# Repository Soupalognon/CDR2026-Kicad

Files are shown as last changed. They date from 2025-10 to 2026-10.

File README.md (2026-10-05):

# Robot CDF 2026

Carte électronique principale du robot **Wall-A**, conçu pour la **Coupe de France de Robotique 2026**.

<p align="center">
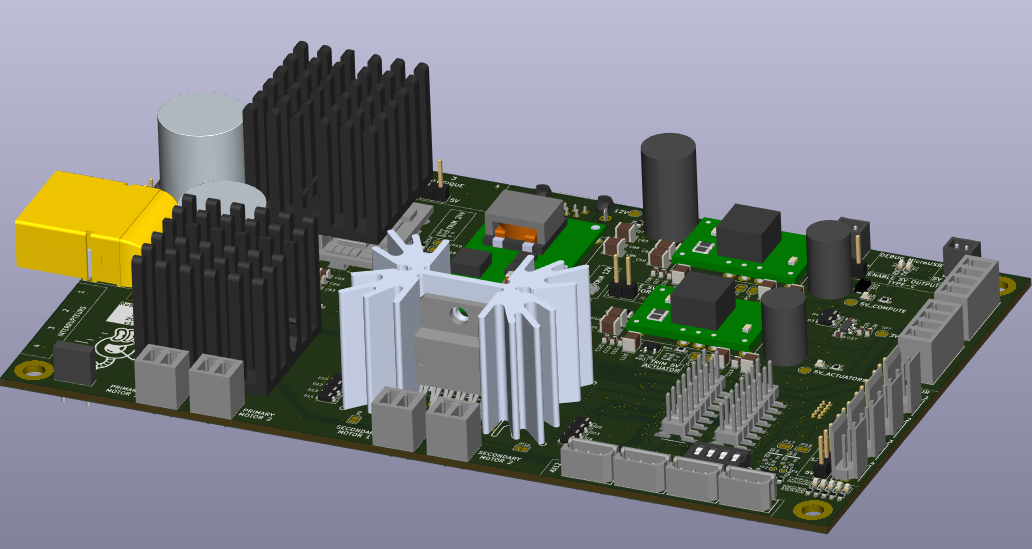
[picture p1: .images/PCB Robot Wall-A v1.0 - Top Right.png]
Vue 3D du PCB Wall-A v1.0
  
</p>

## Description

Ce PCB regroupe tout ce dont le robot a besoin pour fonctionner :

- **Alimentation** : génère les rails 24 V, 12 V, 5 V et 3,3 V à partir de la batterie
- **Moteurs et actionneurs** : commande des moteurs des roues, des moteurs secondaires et des servomoteurs
- **Capteurs** : encodeurs, capteurs de distance, interrupteurs et sondes de température
- **Contrôle bas niveau** : un microcontrôleur STM32F407 pilote le tout en temps réel
- **Liaison avec le PC embarqué** : USB et Ethernet pour le haut niveau. La prise USB Type-C du PC embarqué est une **sortie d'alimentation 5 V**

### Alimentation

La carte est alimentée par la batterie (LiPo 4S 14.8V, connecteur XT90) avec une tension d'entrée de 16 V à 24 V. Elle génère cinq rails avec trois types de convertisseurs :

| Rail | Type de convertisseur | Composant | Courant | Utilisation |
|---|---|---|---|---|
| 24 V | Élévateur (boost) | Module DC/DC ABB ABXS005 | 5,4 A | Moteurs des roues |
| 12 V | Abaisseur (buck) | TI PTN78020W | 5,8 A | Actionneurs (servomoteurs, ...) |
| 5 V actionneurs | Abaisseur (buck) | TI PTN78060W | 3,5 A | Actionneurs (servomoteurs, pompes, canon, télémètres, Lidar, ...) |
| 5 V calcul | Abaisseur (buck) | TI PTN78060W | 3,5 A | PC embarqué et µC |
| 3,3 V | Régulateur linéaire (LDO) | TI TLV75533P | | Logique du µC |

Les rails 24 V, 12 V et 5 V sont réglables par potentiomètre. Les rails 24 V, 12 V et 5 V actionneurs peuvent être activés par le µC. Les rails 5 V et 12 V sont aussi disponibles en sortie sur connecteurs.

### Contrôleurs moteurs

| Moteurs | Driver | Alimentation | Détails |
|---|---|---|---|
| 2 moteurs principaux (roues) | TI DRV8262, double pont en H | 24 V | Transmotec PD4266-24-17-BFEC, avec encodeurs 5 V |
| 2 moteurs secondaires | ST L298N, double pont en H | 5 V ou 12 V | 2 A maximum en continu par moteur |
| 4 servomoteurs AX12/AX18 | Bus série half-duplex (UART) avec adaptation de niveau 3,3 V / 5 V | 12 V | |
| 4 servomoteurs PWM | Signal PWM direct du µC | 5 V ou 12 V | |

Le µC mesure le courant des deux drivers et la température sous chacun d'eux.

### Capteurs

| Capteur | Quantité | Interface | Détails |
|---|---|---|---|
| Encodeurs | 2 | 5 V | Gauche et droite |
| Capteurs de distance Pulse Width | 4 | Largeur d'impulsion | |
| Capteurs de distance analogiques | 4 | ADC, 0 - 3,3 V | |
| Interrupteurs | 4 | Tout ou rien (on/off) | |
| Sondes de température internes | 3 | Thermistances CTN, ADC | Sous le driver moteur principal, sous le driver moteur secondaire, près des alimentations 12 V et 24 V |

### Communications et debug

| Interface | Détails | Utilisation |
|---|---|---|
| USB FS 12 Mb/s | Connecteur USB Type-C | PC embarqué. Cette prise est aussi une **sortie d'alimentation 5 V** |
| Ethernet 100 Mb/s | PHY LAN8742A + RJ45 | PC embarqué |
| UART 115 kbaud | FT231XS (USB-UART) sur micro-USB | Debug |
| Pin headers | Toutes les broches du µC | Accès direct au µC |
| LEDs | 5 LEDs connectées au µC | Debug |

### Informations générales

Le firmware du microcontrôleur est dans le dépôt [CDR2026-Software](https://github.com/Soupalognon/CDR2026-Software).

|  |  |
|---|---|
| Version | v1.0 (septembre 2025) |
| Dimensions | 170 × 100 mm |
| PCB | 4 couches, 1,6 mm |
| Logiciel | KiCad 9 |
| Auteurs | GDU, THO |

## Images

| Dessus | Dessous |
|:---:|:---:|
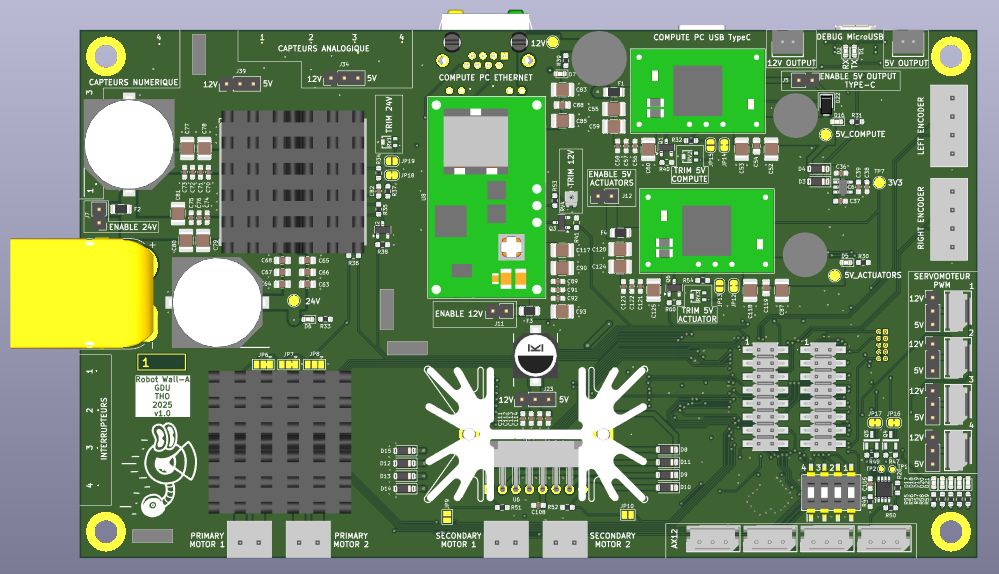
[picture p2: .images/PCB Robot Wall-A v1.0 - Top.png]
Dessus
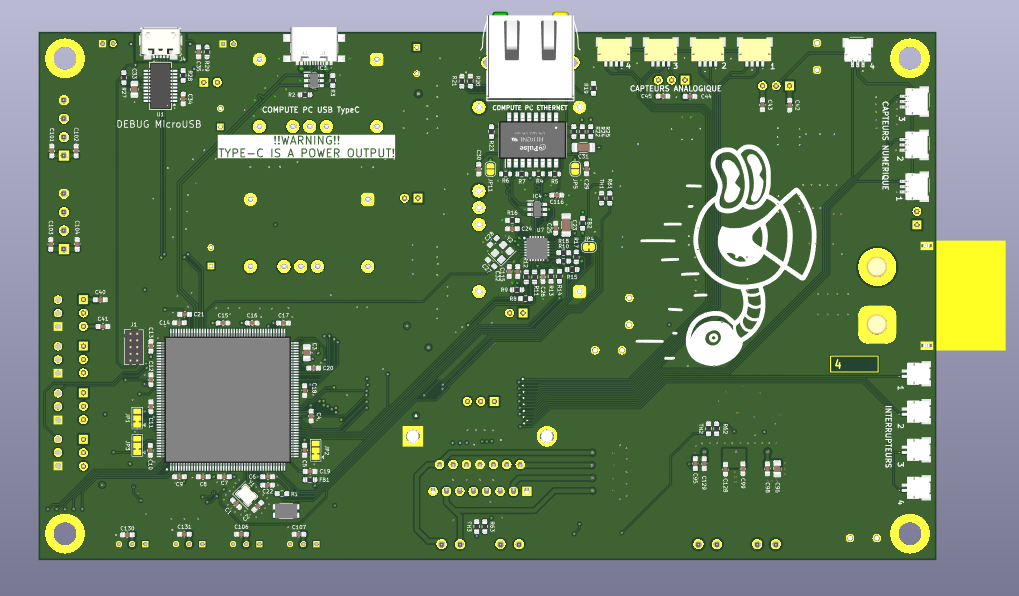
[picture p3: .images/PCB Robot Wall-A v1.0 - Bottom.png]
Dessous
|  |  |
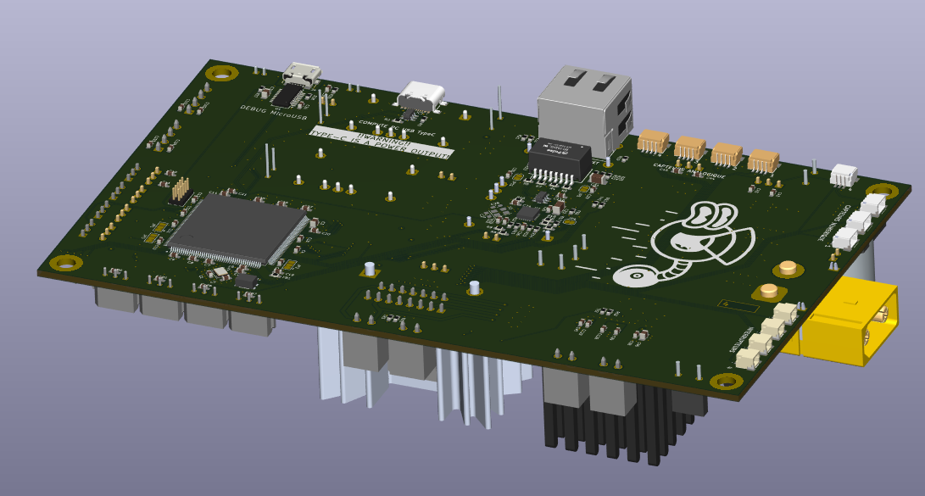
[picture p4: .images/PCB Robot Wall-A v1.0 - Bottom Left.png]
Vue 3D dessous
| Vue 3D dessus |  |

## Composants principaux

| Fonction | Composant |
|---|---|
| Microcontrôleur | STM32F407IGT6 |
| Alimentation 24V | Module DC/DC ABB ABXS005 |
| Alimentation 12V | TI PTN78020W |
| Alimentations 5V (calcul et actionneurs) | 2 × TI PTN78060W |
| Alimentation 3,3V | TI TLV75533P |
| Driver moteurs principaux | TI DRV8262 |
| Driver moteurs secondaires | ST L298N |
| Ethernet | PHY LAN8742A + transformateur H1102NL + RJ45 |
| USB PC embarqué | Connecteur USB Type-C |
| Debug | FT231XS (USB-UART) sur micro-USB |

La liste complète est dans la BOM : [Robot WallA.xlsx](Robot%20WallA/_output/Robot%20WallA.xlsx).

## Organisation du projet

Le schéma est hiérarchique : la feuille racine contient quatre blocs, eux-mêmes découpés en sous-feuilles.

| Bloc | Sous-feuilles |
|---|---|
| `Power` | `Power_Boost_24V`, `Power_Buck_12V`, `Power_Buck_5V_Actuators`, `Power_Buck_5V_Compute` |
| `MCU` | `MCU_Core`, `MCU_Config`, `MCU_Debug`, `MCU_GPIO`, `MCU_Peripherals` |
| `Motor` | `Motor_WheelDriver`, `Motor_Actuators`, `Motor_Encoders` |
| `Sensors` | |

```
.
├── .images/                 Captures du PCB utilisées dans ce README
├── Docs/                    Documents de référence et configuration de commande JLCPCB
├── Robot WallA/             Projet KiCad
│   ├── Robot WallA.kicad_pro / .kicad_sch / .kicad_pcb
│   ├── _Libraries/          Symboles, empreintes et modèles 3D spécifiques
│   └── _output/             Fichiers de fabrication
│       ├── Fab/ et Fab.zip      Gerbers et perçages
│       ├── Robot WallA.pdf      Schéma
│       ├── Robot WallA.xlsx     BOM
│       └── ibom.html            BOM interactive
├── LICENSE
└── README.md
```

## Fabrication

Les fichiers de fabrication sont dans [Robot WallA/_output](Robot%20WallA/_output). La commande a été faite chez JLCPCB, les réglages utilisés sont dans [Docs](Docs). Le dossier contient aussi la configuration du stencil.

Le dossier [Docs](Docs) contient aussi le schéma de la carte STM32F4 Discovery ([MB1137](Docs/MB1137.pdf)), qui sert de référence pour la partie microcontrôleur.

## Licence

Projet sous licence MIT, voir [LICENSE](LICENSE).

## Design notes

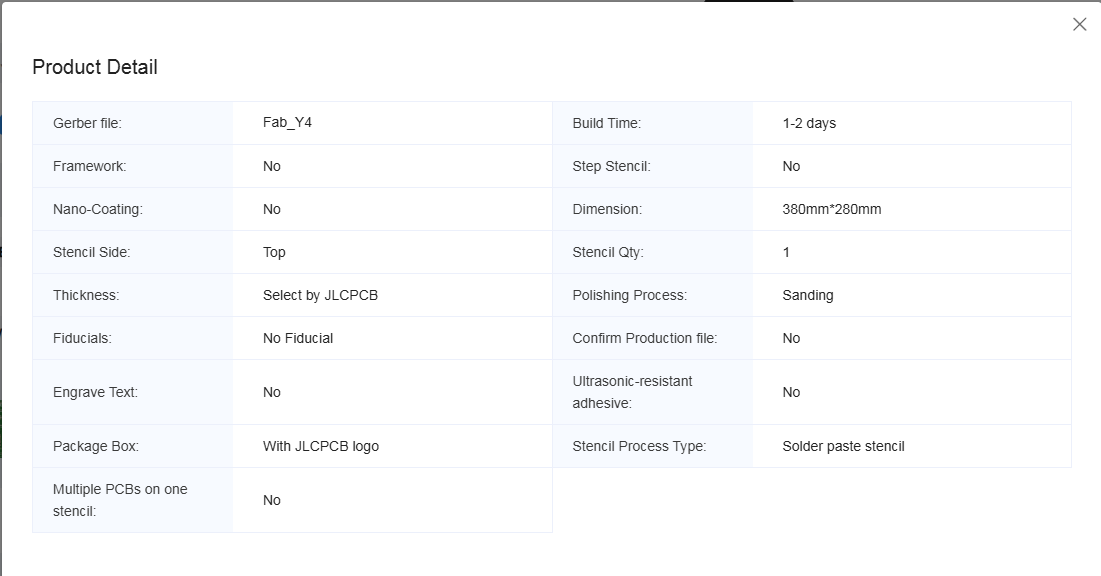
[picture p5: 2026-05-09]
Docs/Config Stencil - PCB WallA - JLCPCB.png

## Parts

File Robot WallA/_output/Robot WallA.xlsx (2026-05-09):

Reference | Qty | Value | Manufacturer_Part_Number | DNP | Exclude from Board | Footprint
C1,C2 | 2 | 12pF | C0603C120F5GACTU |  |  | Capacitor_SMD:C_0603_1608Metric_Pad1.08x0.95mm_HandSolder
C3,C63,C64,C65,C66,C67 | 6 | 4.7uF/50V | GRM21BR61H475ME51L |  |  | Capacitor_SMD:C_0805_2012Metric_Pad1.18x1.45mm_HandSolder
C4,C5,C6,C7,C8,C9,C10,C11,C12,C13,C14,C15,C16,C17,C18,C19,C22,C24,C25,C26,C29,C30,C34,C37,C39,C94,C103,C104,C105,C108,C113,C114,C116 | 33 | 100nF | KGM15BR71H104KT |  |  | Capacitor_SMD:C_0603_1608Metric_Pad1.08x0.95mm_HandSolder
C20,C21 | 2 | 2.2uF | TMK107ABJ225KA-T |  |  | Capacitor_SMD:C_0603_1608Metric_Pad1.08x0.95mm_HandSolder
C23 | 1 | 10uF | CC1206KKX7RDBB102 |  |  | Capacitor_SMD:C_1206_3216Metric_Pad1.33x1.80mm_HandSolder
C27,C28 | 2 | 12pF | C0603C120F5GACTU | DNP |  | Capacitor_SMD:C_0603_1608Metric_Pad1.08x0.95mm_HandSolder
C31 | 1 | 1nF | CC1206KKX7RDBB102 |  |  | Capacitor_SMD:C_1206_3216Metric_Pad1.33x1.80mm_HandSolder
C32,C95,C111,C112 | 4 | 1uF/50V | CL10A105KB8NNNC |  |  | Capacitor_SMD:C_0603_1608Metric_Pad1.08x0.95mm_HandSolder
C33,C54,C68,C88,C96,C119 | 6 | 10nF/50V | CL21B103KBANNNC |  |  | Capacitor_SMD:C_0805_2012Metric_Pad1.18x1.45mm_HandSolder
C35 | 1 | 4.7nF | CC0603JRX7R8BB472 |  |  | Capacitor_SMD:C_0603_1608Metric_Pad1.08x0.95mm_HandSolder
C36,C38,C40,C41,C42,C43,C44,C45,C101,C102,C106,C107,C130,C131 | 14 | 10uF | CL10A106MA8NRNC |  |  | Capacitor_SMD:C_0603_1608Metric_Pad1.08x0.95mm_HandSolder
C51,C86 | 2 | 100uF | EEU-FC1V101 |  |  | SamacSys_Parts:CAPPRD350W65D800H1250
C52,C53,C59,C60,C77,C78,C79,C80,C81,C83,C85,C87,C93,C117,C118,C124,C125 | 17 | 4.7uF/50V | GRM32ER71H475KA88L |  |  | Capacitor_SMD:C_1210_3225Metric_Pad1.33x2.70mm_HandSolder
C55,C90,C120 | 3 | 2.2uF/50V | C3225X7R1H225K250AB |  |  | Capacitor_SMD:C_1210_3225Metric_Pad1.33x2.70mm_HandSolder
C56,C57,C58,C70,C71,C72,C73,C74,C75,C76,C89,C91,C92,C121,C122,C123 | 16 | 47nF/50V | CC0603KPX7R9BB473 |  |  | Capacitor_SMD:C_0603_1608Metric_Pad1.08x0.95mm_HandSolder
C62,C69 | 2 | 470uF/50V | EMVE500ARA471MLH0S |  |  | SamacSys_Parts:CAPAE1700X1700N
C82,C115 | 2 | 470pF | C0603C471K5RACTU |  |  | Capacitor_SMD:C_0603_1608Metric_Pad1.08x0.95mm_HandSolder
C84 | 1 | 330uF | EEU-FC1V331 |  |  | SamacSys_Parts:CAPPRD500W65D1000H1800
C98,C99,C100,C128,C129 | 5 | 100nF/50V | KGM15BR71H104KT |  |  | Capacitor_SMD:C_0603_1608Metric_Pad1.08x0.95mm_HandSolder
C109 | 1 | 100uF | EDK107M050A9MAA |  |  | SamacSys_Parts:CAPAE830X1050N
D1,D19 | 2 | LED_GREEN | APT1608LZGCK |  |  | LED_SMD:LED_0603_1608Metric
D2,D5,D6,D7,D16,D21 | 6 | LED_RED | LS L29K-G1J2-1 |  |  | LED_SMD:LED_0603_1608Metric
D3,D4 | 2 | SS0520_R1_00001 | SS0520_R1_00001 |  |  | Diode_SMD:D_SOD-123
D8,D9,D10,D11,D12,D13,D14,D15 | 8 | 1N5819 | 1N5819HW-7-F |  |  | Diode_SMD:D_SOD-123
D17 | 1 | LED_YELLOW | SML-D12W8WT86C |  |  | LED_SMD:LED_0603_1608Metric
D18 | 1 | LED_ORANGE | CSL1901DW1 |  |  | LED_SMD:LED_0603_1608Metric
D20 | 1 | LED_BLUE | APT1608LVBC/D |  |  | LED_SMD:LED_0603_1608Metric
D22 | 1 | Diode 3A | SS3P4-M3/84A |  |  | Diode_SMD:D_SMP_DO-220AA
F1,F3,F4 | 3 | Fuse 3A | JB12F3001R |  |  | Fuse:Fuse_1206_3216Metric
F2 | 1 | Fuse 5A | JB12S5001R |  |  | Fuse:Fuse_1206_3216Metric
FB1 | 1 | Bead 600R | FCM 1608KF-601T03 |  |  | Resistor_SMD:R_0603_1608Metric_Pad0.98x0.95mm_HandSolder
FB2 | 1 | FerriteBead | FCM 1608KF-601T03 |  |  | Resistor_SMD:R_0603_1608Metric_Pad0.98x0.95mm_HandSolder
H5 | 1 | Heatsink | 647-10ABEP |  |  | SamacSys_Parts:64710ABEP
H6 | 1 | ThermalPad | SPA2000-0.015-AC-62 |  | Excluded from board
H7 | 1 | ThermalPad | 404035125 |  | Excluded from board
H8,H9 | 2 | Heatsink | 374524B60023G |  |  | Library:374524B60023G
IC1 | 1 | STM32F407IGT6 | STM32F407IGT6 |  |  | SamacSys_Parts:QFP50P2600X2600X160-176N
IC2 | 1 | DS04-254-2-04BK-SMT | DS04-254-2-04BK-SMT |  |  | SamacSys_Parts:SOP254P990X430-8N
IC3,IC4 | 2 | USBLC6-4SC6 | USBLC6-4SC6 |  |  | SamacSys_Parts:SOT95P280X145-6N
IC6 | 1 | TLV75533PDBVR | TLV75533PDBVR |  |  | SamacSys_Parts:SOT95P280X145-5N
IC7 | 1 | ABXS005A4X341-SRZ | ABXS005A4X341-SRZ |  |  | SamacSys_Parts:ABXS005A4X341SRZ
IC8 | 1 | DRV8262DDVR | DRV8262DDVR |  |  | SamacSys_Parts:SOP64P810X120-44N
IC9 | 1 | 74LVC2G241DP_125 | 74LVC2G241DP_125 |  |  | SamacSys_Parts:SOP65P400X110-8N
J2 | 1 | USB4216-03-A | USB4216-03-A |  |  | SamacSys_Parts:USB421603A
J3 | 1 | SS-90000-009 | SS-90000-009 |  |  | SamacSys_Parts:SS90000009
J4 | 1 | USB_B_Micro | USB3140-30-0230-0-C |  |  | SamacSys_Parts:USB_Micro-B_Molex_47346-0001
J6,J13 | 2 | 10129383-916001ALF | 10129383-916001ALF |  |  | SamacSys_Parts:10129383916001ALF
J8 | 1 | XT90PW_M | XT90PW-M |  |  | Connector_AMASS:AMASS_XT90PW-M_1x02_P10.90mm_Horizontal
J9,J10 | 2 | Conn_01x02 | B2B-PH-K-S(LF)(SN) |  |  | SamacSys_Parts:SHDR2W50P0X200_1X2_590X450X600P
J15,J16,J30,J31 | 4 | 39501-1002 | 39501-1002 |  |  | SamacSys_Parts:395011002
J17,J18 | 2 | 39501-1004 | 39501-1004 |  |  | SamacSys_Parts:395011004
J19,J20,J21,J22 | 4 | 1145117 | '22-03-5035 |  |  | SamacSys_Parts:SHDR3W60P0X250_1X3_990X490X590P
J24,J26,J28,J33 | 4 | 281695-3 | 281695-3 |  |  | SamacSys_Parts:SHDR3W65P0X254_1X3_762X508X1150P
J35,J36,J37,J45 | 4 | SM04B-SRSS-TB | SM04B-SRSS-TB |  |  | SamacSys_Parts:SM04BSRSSTB
J38,J44,J46,J47 | 4 | SM02B-SRSS-TB_LF__SN_ | SM02B-SRSS-TB(LF)(SN) |  |  | SamacSys_Parts:SM02BSRSSTBLFSN
J40,J41,J42,J43 | 4 | SM03B-SRSS-TB_LF__SN_ | SM03B-SRSS-TB(LF)(SN) |  |  | SamacSys_Parts:SM03BSRSSTBLFSN
N1,N2,N3,N4,N5,N6,N7,N8,N9,N10,N17 | 11 | Cavalier_Alim | 15-29-1024 |  | Excluded from board
N11,N12,N13,N14 | 4 | Connecteurs | 39503-2002 |  | Excluded from board
N15,N16 | 2 | Connecteurs | 39503-2004 |  | Excluded from board
Q1,Q2,Q3,Q6 | 4 | BSS138 | BSS138 |  |  | Package_TO_SOT_SMD:SOT-23
Q4,Q5 | 2 | BSS119 | BSS119NH6327XTSA1 | DNP |  | SamacSys_Parts:SOT95P260X110-3N
R1,R36,R40,R41,R42,R47,R49,R60 | 8 | 10k | 667-ERJ-3GEYJ103V | DNP |  | Resistor_SMD:R_0603_1608Metric_Pad0.98x0.95mm_HandSolder
R2,R3,R39 | 3 | 5.1k | CRCW06035K10FKEA |  |  | Resistor_SMD:R_0603_1608Metric_Pad0.98x0.95mm_HandSolder
R4,R5,R6,R7 | 4 | 50R | CRCW060350R0FKTA |  |  | Resistor_SMD:R_0603_1608Metric
R8,R9,R10,R13,R20,R38,R43,R48,R50,R61,R62,R63 | 12 | 10k | 667-ERJ-3GEYJ103V |  |  | Resistor_SMD:R_0603_1608Metric_Pad0.98x0.95mm_HandSolder
R11,R12,R14,R18 | 4 | 33R | CRCW060333R0JNEA |  |  | Resistor_SMD:R_0603_1608Metric_Pad0.98x0.95mm_HandSolder
R15,R17 | 2 | 1k5 | RC0603JR-071K5L |  |  | Resistor_SMD:R_0603_1608Metric_Pad0.98x0.95mm_HandSolder
R16 | 1 | 12k1 | ERJ-3EKF1212V |  |  | Resistor_SMD:R_0603_1608Metric_Pad0.98x0.95mm_HandSolder
R19,R21 | 2 | 270R | RE0603FRE07270RL |  |  | Resistor_SMD:R_0603_1608Metric_Pad0.98x0.95mm_HandSolder
R22,R23,R24,R25 | 4 | 75R | CRCW060375R0FKEAC |  |  | Resistor_SMD:R_0603_1608Metric_Pad0.98x0.95mm_HandSolder
R27 | 1 | 402R | CR0603-FX-4020ELF |  |  | Resistor_SMD:R_0603_1608Metric_Pad0.98x0.95mm_HandSolder
R28 | 1 | 549R | RC0603FR-07549RL |  |  | Resistor_SMD:R_0603_1608Metric_Pad0.98x0.95mm_HandSolder
R29 | 1 | 1Meg | ERJ-3GEYJ105V |  |  | Resistor_SMD:R_0603_1608Metric_Pad0.98x0.95mm_HandSolder
R30,R31 | 2 | 1.6k | ERJ-3EKF1601V |  |  | Resistor_SMD:R_0603_1608Metric_Pad0.98x0.95mm_HandSolder
R32,R54 | 2 | 21k | RC0603FR-0721KL |  |  | Resistor_SMD:R_0603_1608Metric_Pad0.98x0.95mm_HandSolder
R33 | 1 | 11.3k | CRCW060311K3FKEA |  |  | Resistor_SMD:R_0603_1608Metric_Pad0.98x0.95mm_HandSolder
R34 | 1 | 200k | CRCW0603200KFKEC |  |  | Resistor_SMD:R_0603_1608Metric_Pad0.98x0.95mm_HandSolder
R35 | 1 | 100k | RCA0603100KFKEAHP |  |  | Resistor_SMD:R_0603_1608Metric_Pad0.98x0.95mm_HandSolder
R37 | 1 | 10,553k/0.5% | RC0603DR-0710K5L |  |  | Resistor_SMD:R_0603_1608Metric_Pad0.98x0.95mm_HandSolder
R44,R45 | 2 | 3,09k | CRCW06033K09FKEA |  |  | Resistor_SMD:R_0603_1608Metric_Pad0.98x0.95mm_HandSolder
R46 | 1 | 100k | RCA0603100KFKEAHP | DNP |  | Resistor_SMD:R_0603_1608Metric_Pad0.98x0.95mm_HandSolder
R51,R52 | 2 | 0.5R/0.1% | CSR0603FKR500 |  |  | Resistor_SMD:R_0603_1608Metric_Pad0.98x0.95mm_HandSolder
R53,R59 | 2 | 549R | RC0603FR-07549RL |  |  | Resistor_SMD:R_0603_1608Metric_Pad0.98x0.95mm_HandSolder
R55 | 1 | 649R | RC0603FR-07649RL |  |  | Resistor_SMD:R_0603_1608Metric_Pad0.98x0.95mm_HandSolder
R56 | 1 | 750R | RC0603FR-10750RL |  |  | Resistor_SMD:R_0603_1608Metric_Pad0.98x0.95mm_HandSolder
R57 | 1 | 324R | RC0603FR-07324RL |  |  | Resistor_SMD:R_0603_1608Metric_Pad0.98x0.95mm_HandSolder
R58 | 1 | 330R | AF0603JR-07330RL |  |  | Resistor_SMD:R_0603_1608Metric_Pad0.98x0.95mm_HandSolder
RV1,RV2,RV3 | 3 | Trim 2k | TC42X-2-202E | DNP |  | SamacSys_Parts:TC42X2202E
RV4 | 1 | Trim 2k | TC42X-2-202E |  |  | SamacSys_Parts:TC42X2202E
SW1 | 1 | Switch | KMR231NGLFS |  |  | SamacSys_Parts:KMR231NGLFS
T1 | 1 | H1102NL | H1102NL |  |  | SamacSys_Parts:SOIC127P940X597-16N
TH1,TH2,TH3 | 3 | Thermistor_NTC | NCU18XH103E60RB |  |  | Resistor_SMD:R_0603_1608Metric_Pad0.98x0.95mm_HandSolder
U1 | 1 | FT231XS | FT231XS-R |  |  | Package_SO:SSOP-20_3.9x8.7mm_P0.635mm
U2,U3,U4,U5 | 4 | 125700D00000G | 125700D00000G |  |  | SamacSys_Parts:125700D00000G
U6 | 1 | L298N | L298N |  |  | Package_TO_SOT_THT:TO-220-15_P2.54x5.08mm_StaggerOdd_Lead4.58mm_Vertical
U7 | 1 | LAN8742A | LAN8742A-CZ |  |  | SamacSys_Parts:QFN50P400X400X100-25N-D
U8 | 1 | PTN78020W | PTN78020WAD |  |  | Module:Texas_EUK_R-PDSS-T7_THT
U9,U10 | 2 | PTN78060W_EUW-7 | PTN78060WAD |  |  | Module:Texas_EUW_R-PDSS-T7_THT
Y1 | 1 | Crystal_GND24 | ECS-250-10-33B-CWN-TR3 |  |  | Crystal:Crystal_SMD_3225-4Pin_3.2x2.5mm
Y2 | 1 | Crystal_GND24 | ECS-250-10-33B-CWN-TR3 | DNP |  | Crystal:Crystal_SMD_3225-4Pin_3.2x2.5mm
 |  | XT90PW | TME

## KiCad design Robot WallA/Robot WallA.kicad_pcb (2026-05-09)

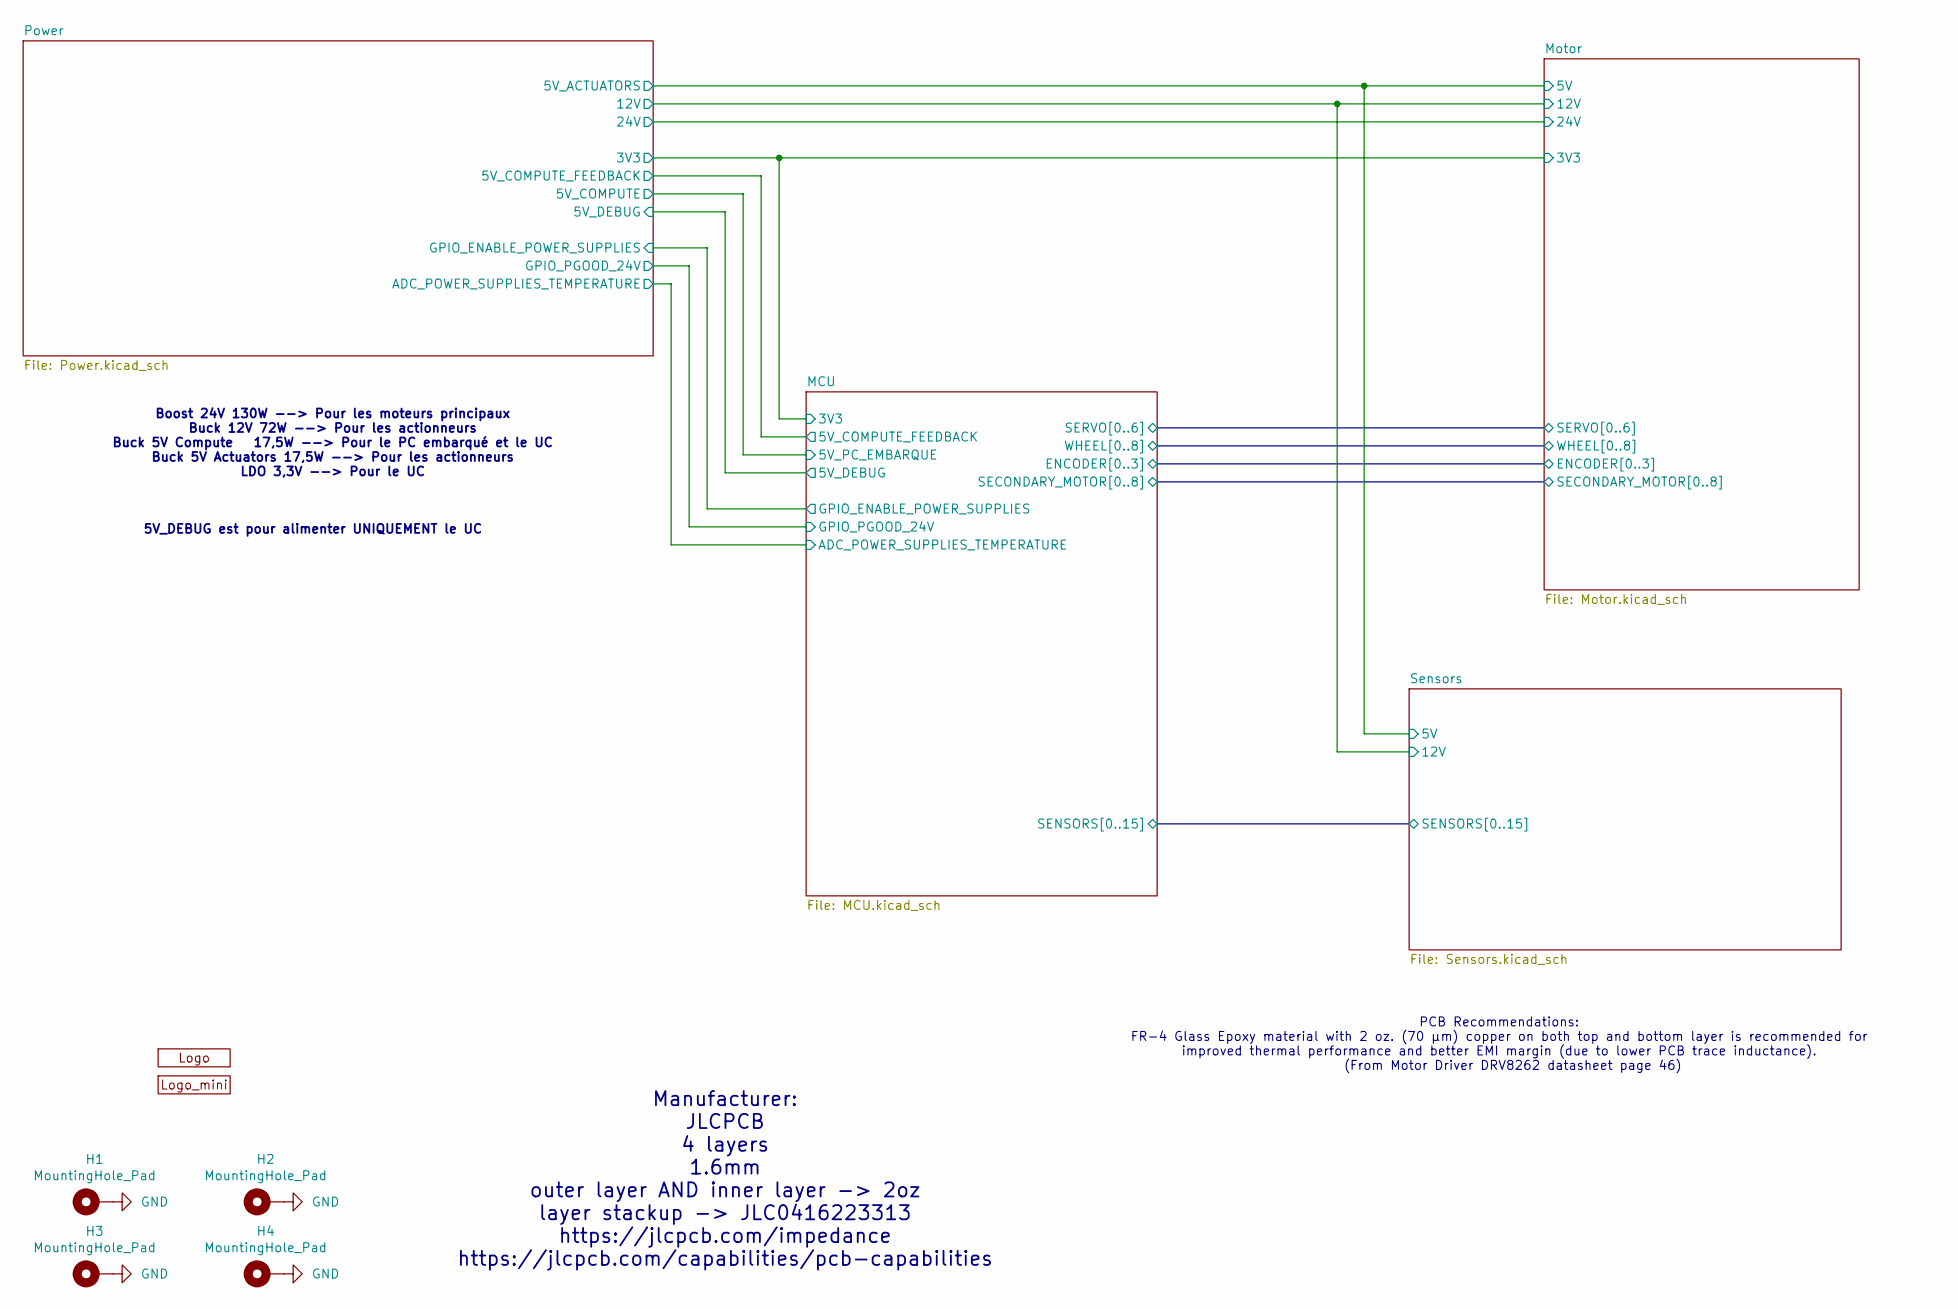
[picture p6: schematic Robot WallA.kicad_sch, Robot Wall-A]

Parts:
H1, H2, H3, H4: MountingHole_Pad; MountingHole_4.3mm_M4_DIN965_Pad_TopBottom
U11: Logo_Wall-A
U12: Logo_mini_Wall-A

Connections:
GND: H1.1, H2.1, H3.1, H4.1; also elsewhere on the board

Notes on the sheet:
5V_DEBUG est pour alimenter UNIQUEMENT le UC
PCB Recommendations: FR-4 Glass Epoxy material with 2 oz. (70 μm) copper on both top and bottom layer is recommended for improved thermal performance and better EMI margin (due to lower PCB trace inductance). (From Motor Driver DRV8262 datasheet page 46)
Boost 24V 130W --> Pour les moteurs principaux Buck 12V 72W --> Pour les actionneurs Buck 5V Compute 17,5W --> Pour le PC embarqué et le UC Buck 5V Actuators 17,5W --> Pour les actionneurs LDO 3,3V --> Pour le UC
Manufacturer: JLCPCB 4 layers 1.6mm outer layer AND inner layer -> 2oz layer stackup -> JLC0416223313 https://jlcpcb.com/impedance https://jlcpcb.com/capabilities/pcb-capabilities

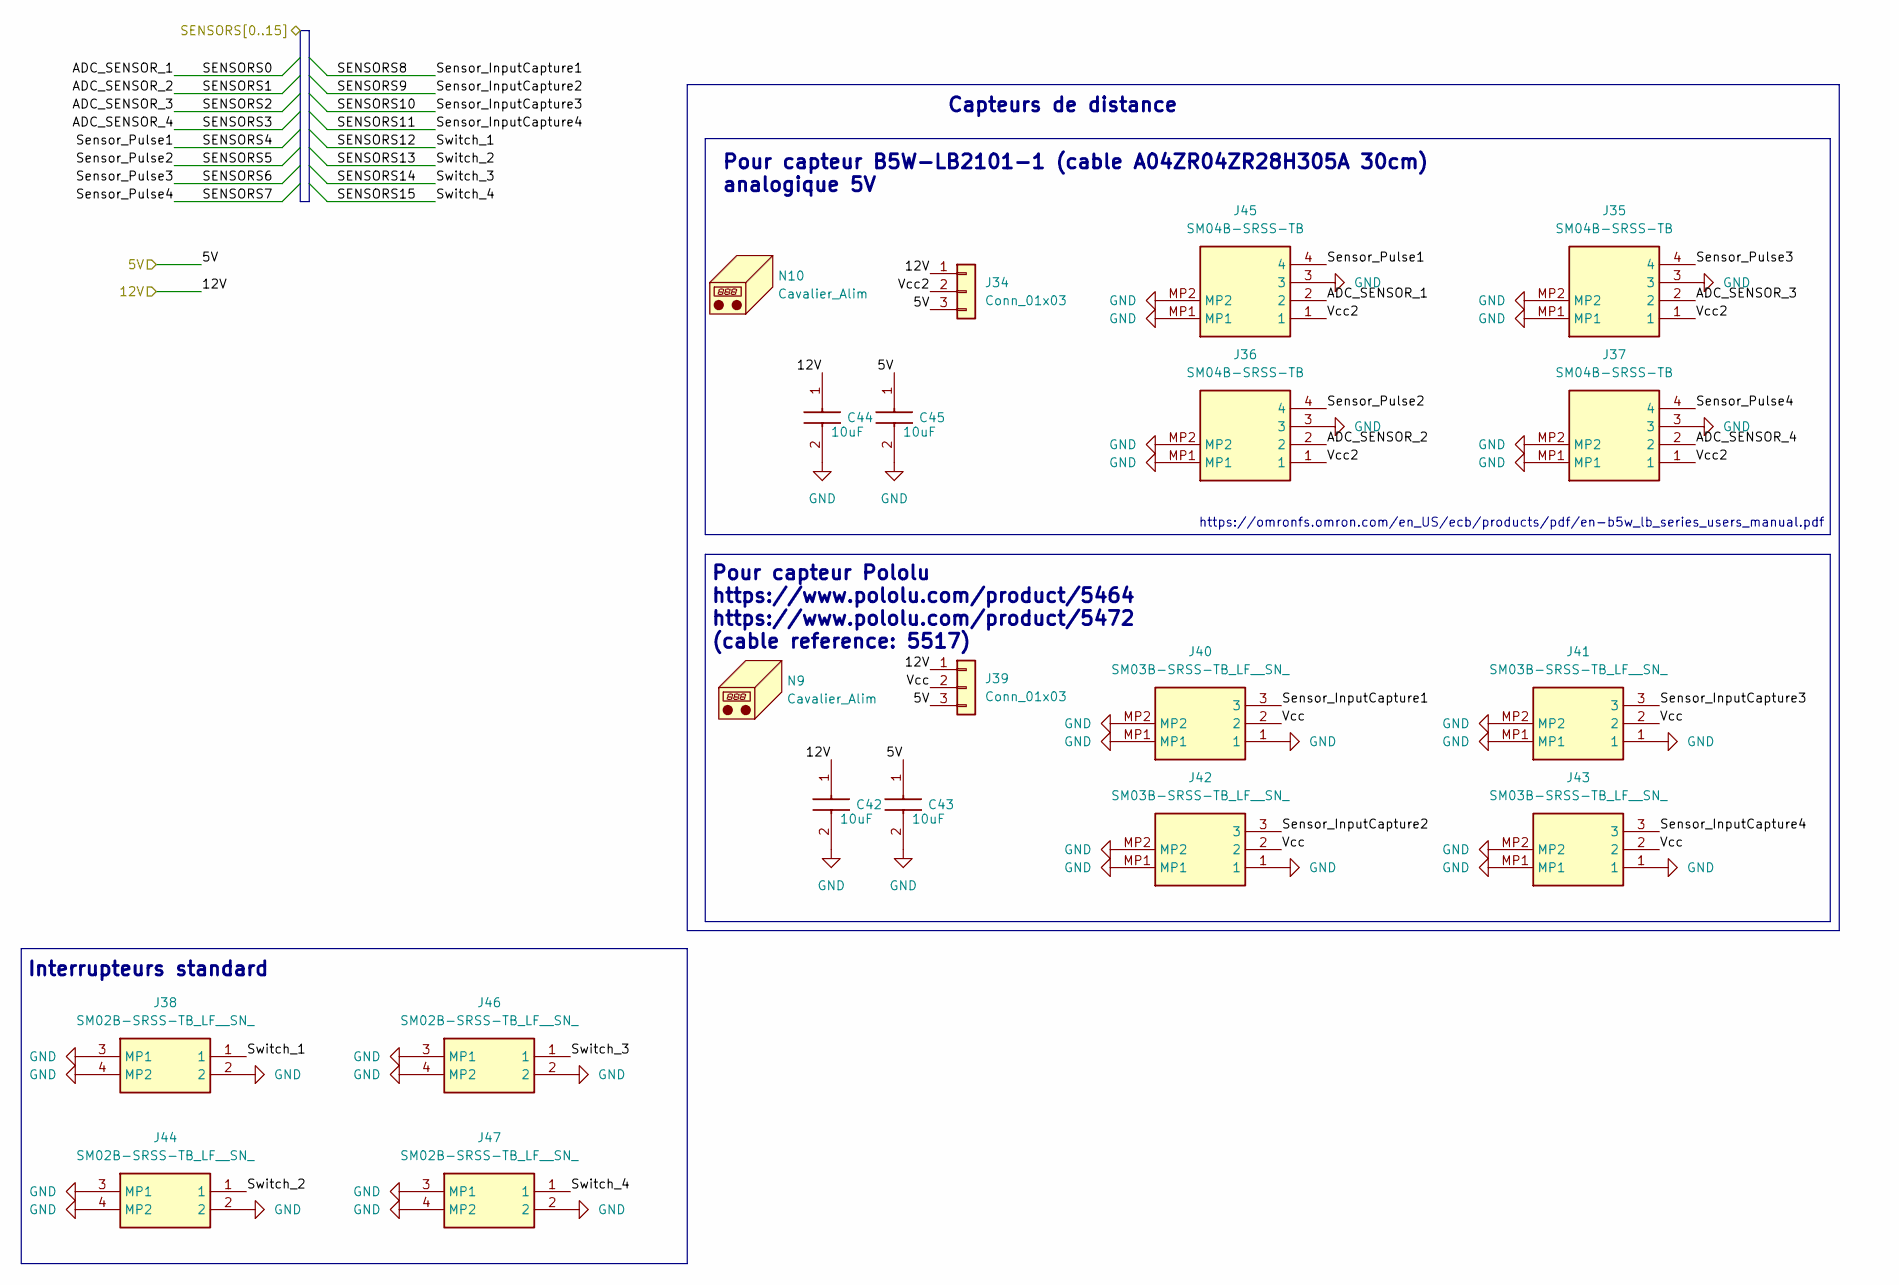
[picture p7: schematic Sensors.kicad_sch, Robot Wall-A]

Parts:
C42, C43, C44, C45: 10uF; C_0603_1608Metric_Pad1.08x0.95mm_HandSolder; Manufacturer_Part_Number CL10A106MA8NRNC
J34, J39: Conn_01x03; PinHeader_1x03_P2.54mm_Vertical
J35, J36, J37, J45: SM04B-SRSS-TB; SM04BSRSSTB; Manufacturer_Part_Number SM04B-SRSS-TB
J38, J44, J46, J47: SM02B-SRSS-TB_LF__SN_; SM02BSRSSTBLFSN; Manufacturer_Part_Number SM02B-SRSS-TB(LF)(SN); Mouser Part Number N/A
J40, J41, J42, J43: SM03B-SRSS-TB_LF__SN_; SM03BSRSSTBLFSN; Manufacturer_Part_Number SM03B-SRSS-TB(LF)(SN); Mouser Part Number N/A
N9, N10: Cavalier_Alim; Manufacturer_Part_Number 15-29-1024

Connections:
/MCU/SENSORS0: J45.2; also elsewhere on the board
/MCU/SENSORS1: J36.2; also elsewhere on the board
/MCU/SENSORS2: J35.2; also elsewhere on the board
/MCU/SENSORS3: J37.2; also elsewhere on the board
/MCU/SENSORS4: J45.4; also elsewhere on the board
/MCU/SENSORS5: J36.4; also elsewhere on the board
/MCU/SENSORS6: J35.4; also elsewhere on the board
/MCU/SENSORS7: J37.4; also elsewhere on the board
/MCU/SENSORS8: J40.3; also elsewhere on the board
/MCU/SENSORS9: J42.3; also elsewhere on the board
/MCU/SENSORS10: J41.3; also elsewhere on the board
/MCU/SENSORS11: J43.3; also elsewhere on the board
/MCU/SENSORS12: J38.1; also elsewhere on the board
/MCU/SENSORS13: J44.1; also elsewhere on the board
/MCU/SENSORS14: J46.1; also elsewhere on the board
/MCU/SENSORS15: J47.1; also elsewhere on the board
/Motor/5V: C43.1, C45.1, J34.3, J39.3; also elsewhere on the board
/Power/12V: C42.1, C44.1, J34.1, J39.1; also elsewhere on the board
/Sensors/Vcc: J39.2, J40.2, J41.2, J42.2, J43.2
/Sensors/Vcc2: J34.2, J35.1, J36.1, J37.1, J45.1
GND: C42.2, C43.2, C44.2, C45.2, J35.3, J35.MP1, J35.MP2, J36.3, J36.MP1, J36.MP2, J37.3, J37.MP1, J37.MP2, J38.2, J38.3 (MP1), J38.4 (MP2), J40.1, J40.MP1, J40.MP2, J41.1, J41.MP1, J41.MP2, J42.1, J42.MP1, J42.MP2, J43.1, J43.MP1, J43.MP2, J44.2, J44.3 (MP1), J44.4 (MP2), J45.3, J45.MP1, J45.MP2, J46.2, J46.3 (MP1), J46.4 (MP2), J47.2, J47.3 (MP1), J47.4 (MP2); also elsewhere on the board

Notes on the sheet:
Pour capteur Pololu https://www.pololu.com/product/5464 https://www.pololu.com/product/5472 (cable reference: 5517)
Interrupteurs standard
Pour capteur B5W-LB2101-1 (cable A04ZR04ZR28H305A 30cm) analogique 5V
Capteurs de distance
https://omronfs.omron.com/en_US/ecb/products/pdf/en-b5w_lb_series_users_manual.pdf

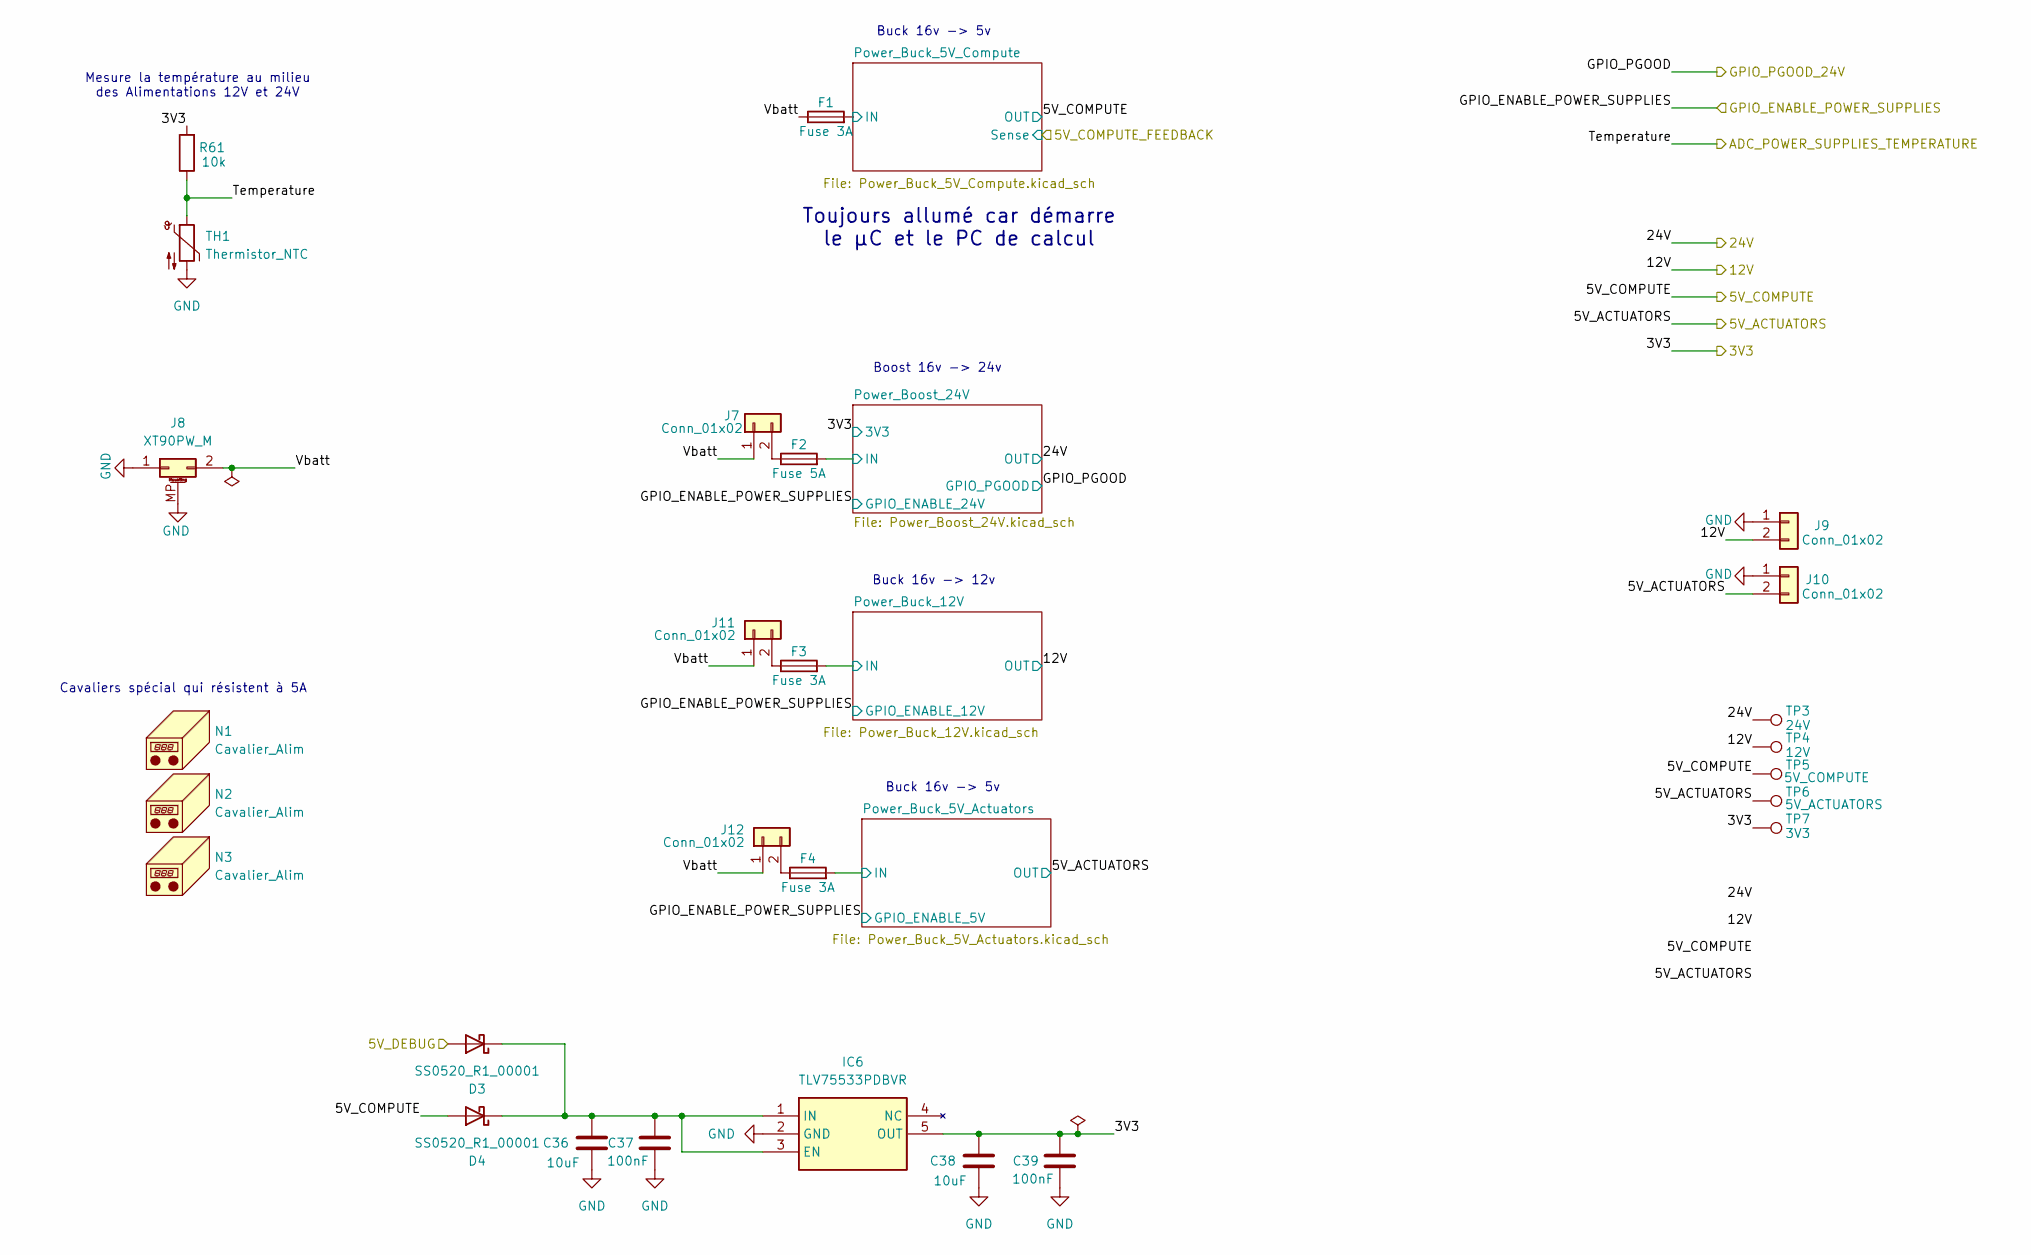
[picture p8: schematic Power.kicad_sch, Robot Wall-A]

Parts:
C36, C38: 10uF; C_0603_1608Metric_Pad1.08x0.95mm_HandSolder; Manufacturer_Part_Number CL10A106MA8NRNC
C37, C39: 100nF; C_0603_1608Metric_Pad1.08x0.95mm_HandSolder; Manufacturer_Part_Number KGM15BR71H104KT
D3, D4: SS0520_R1_00001; D_SOD-123; Manufacturer_Part_Number SS0520_R1_00001
F1, F3, F4: Fuse 3A; Fuse_1206_3216Metric; Manufacturer_Part_Number JB12F3001R
F2: Fuse 5A; Fuse_1206_3216Metric; Manufacturer_Part_Number JB12S5001R
IC6: TLV75533PDBVR; SOT95P280X145-5N; Manufacturer_Part_Number TLV75533PDBVR
J7, J11, J12: Conn_01x02; PinHeader_1x02_P2.54mm_Vertical
J8: XT90PW_M; AMASS_XT90PW-M_1x02_P10.90mm_Horizontal; Manufacturer_Part_Number XT90PW-M
J9, J10: Conn_01x02; SHDR2W50P0X200_1X2_590X450X600P; Manufacturer_Part_Number B2B-PH-K-S(LF)(SN)
N1, N2, N3: Cavalier_Alim; Manufacturer_Part_Number 15-29-1024
R61: 10k; R_0603_1608Metric_Pad0.98x0.95mm_HandSolder; Manufacturer_Part_Number 667-ERJ-3GEYJ103V
TH1: Thermistor_NTC; R_0603_1608Metric_Pad0.98x0.95mm_HandSolder; Manufacturer_Part_Number NCU18XH103E60RB
TP3: 24V; TestPoint_Pad_D2.0mm
TP4: 12V; TestPoint_Pad_D2.0mm
TP5: 5V_COMPUTE; TestPoint_Pad_D2.0mm
TP6: 5V_ACTUATORS; TestPoint_Pad_D2.0mm
TP7: 3V3; TestPoint_Pad_D2.0mm

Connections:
/MCU/3V3: C38.1, C39.1, IC6.5 (OUT), R61.2, TP7.1; also elsewhere on the board
/MCU/5V_PC_EMBARQUE: D4.2 (A), TP5.1; also elsewhere on the board
/MCU/MCU_Debug/5V_DEBUG: D3.2 (A); also elsewhere on the board
/Motor/5V: J10.2, TP6.1; also elsewhere on the board
/Power/12V: J9.2, TP4.1; also elsewhere on the board
/Power/24V: TP3.1; also elsewhere on the board
/Power/Power_Boost_24V/IN: F2.2; also elsewhere on the board
/Power/Power_Buck_5V_Actuators/IN: F4.2; also elsewhere on the board
/Power/Power_Buck_5V_Compute/IN: F1.2; also elsewhere on the board
/Power/Power_Buck_12V/IN: F3.2; also elsewhere on the board
/Power/Temperature: R61.1, TH1.1; also elsewhere on the board
/Power/Vbatt: F1.1, J7.1, J8.2, J11.1, J12.1
GND: C36.2, C37.2, C38.2, C39.2, IC6.2 (GND), J8.1, J8.MP (MountPin), J9.1, J10.1, TH1.2; also elsewhere on the board
unnamed: C36.1, C37.1, D3.1 (K), D4.1 (K), IC6.1 (IN), IC6.3 (EN)
unnamed: F2.1, J7.2
unnamed: F3.1, J11.2
unnamed: F4.1, J12.2

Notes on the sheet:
Cavaliers spécial qui résistent à 5A
Buck 16v -> 12v
Mesure la température au milieu des Alimentations 12V et 24V
Toujours allumé car démarre le µC et le PC de calcul
Boost 16v -> 24v
Buck 16v -> 5v

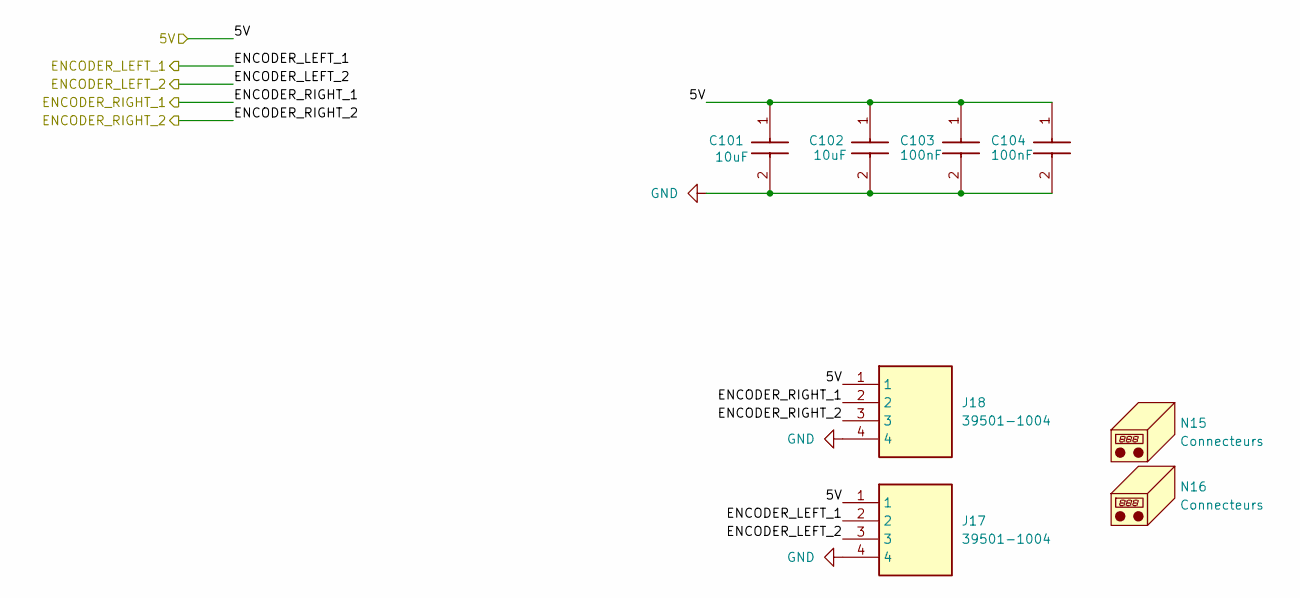
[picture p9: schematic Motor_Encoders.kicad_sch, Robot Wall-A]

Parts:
C101, C102: 10uF; C_0603_1608Metric_Pad1.08x0.95mm_HandSolder; Manufacturer_Part_Number CL10A106MA8NRNC
C103, C104: 100nF; C_0603_1608Metric_Pad1.08x0.95mm_HandSolder; Manufacturer_Part_Number KGM15BR71H104KT
J17, J18: 39501-1004; 395011004; Manufacturer_Part_Number 39501-1004
N15, N16: Connecteurs; Manufacturer_Part_Number 39503-2004

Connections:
/MCU/ENCODER0: J18.2; also elsewhere on the board
/MCU/ENCODER1: J18.3; also elsewhere on the board
/MCU/ENCODER2: J17.2; also elsewhere on the board
/MCU/ENCODER3: J17.3; also elsewhere on the board
/Motor/5V: C101.1, C102.1, C103.1, C104.1, J17.1, J18.1; also elsewhere on the board
GND: C101.2, C102.2, C103.2, C104.2, J17.4, J18.4; also elsewhere on the board

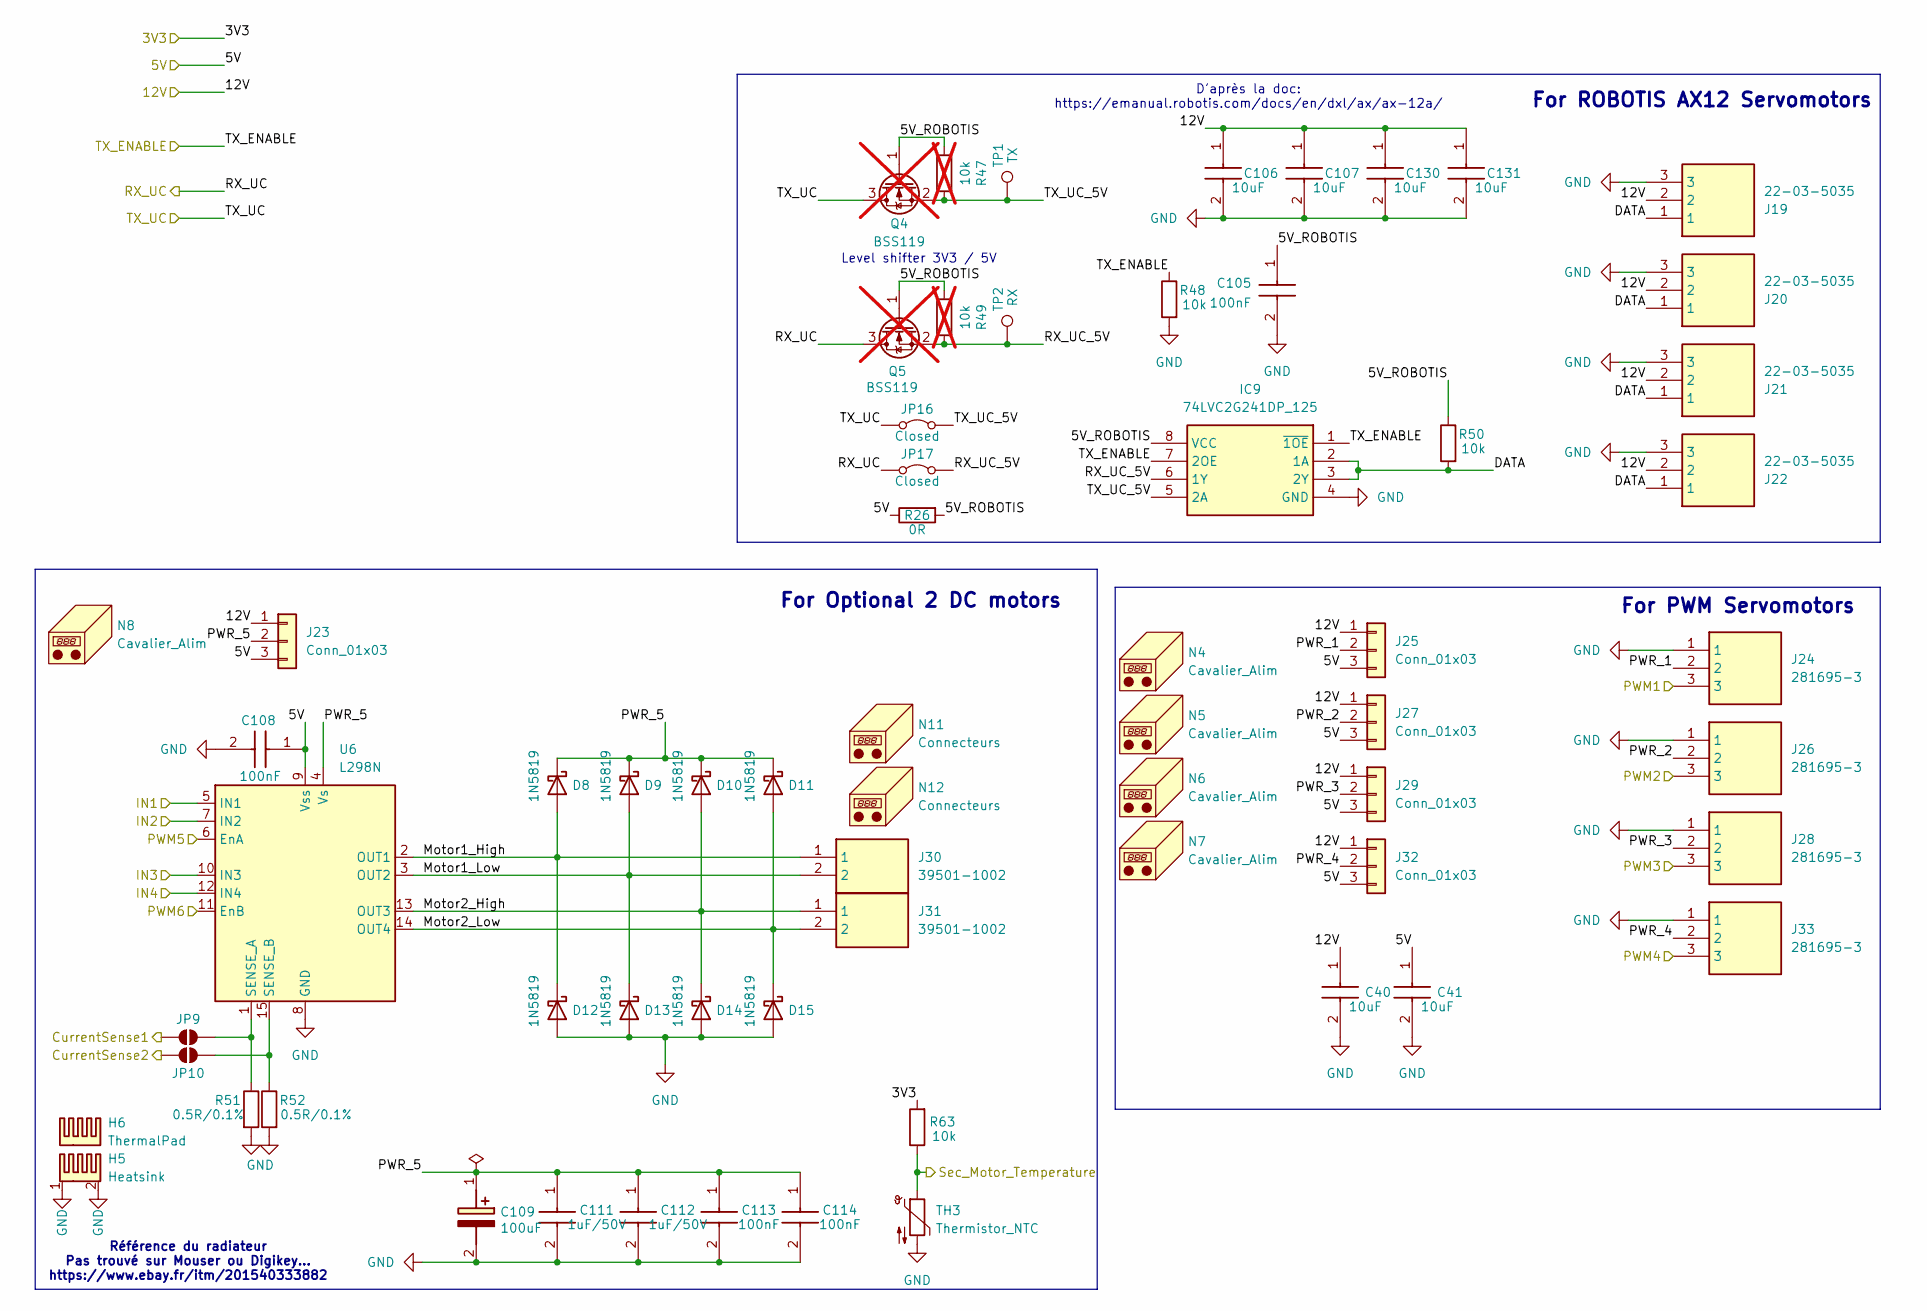
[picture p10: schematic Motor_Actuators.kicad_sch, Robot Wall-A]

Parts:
C40, C41, C106, C107, C130, C131: 10uF; C_0603_1608Metric_Pad1.08x0.95mm_HandSolder; Manufacturer_Part_Number CL10A106MA8NRNC
C105, C108, C113, C114: 100nF; C_0603_1608Metric_Pad1.08x0.95mm_HandSolder; Manufacturer_Part_Number KGM15BR71H104KT
C109: 100uF; CAPAE830X1050N; Manufacturer_Part_Number EDK107M050A9MAA
C111, C112: 1uF/50V; C_0603_1608Metric_Pad1.08x0.95mm_HandSolder; Manufacturer_Part_Number CL10A105KB8NNNC
D8, D9, D10, D11, D12, D13, D14, D15: 1N5819; D_SOD-123; Manufacturer_Part_Number 1N5819HW-7-F
H5: Heatsink; 64710ABEP; Manufacturer_Part_Number 647-10ABEP
H6: ThermalPad; Manufacturer_Part_Number SPA2000-0.015-AC-62
IC9: 74LVC2G241DP_125; SOP65P400X110-8N; Manufacturer_Part_Number 74LVC2G241DP_125
J19, J20, J21, J22: 22-03-5035; SHDR3W60P0X250_1X3_990X490X590P; Manufacturer_Part_Number '22-03-5035
J23, J25, J27, J29, J32: Conn_01x03; PinHeader_1x03_P2.54mm_Vertical
J24, J26, J28, J33: 281695-3; SHDR3W65P0X254_1X3_762X508X1150P; Manufacturer_Part_Number 281695-3
J30, J31: 39501-1002; 395011002; Manufacturer_Part_Number 39501-1002
JP9, JP10: SolderJumper; SolderJumper-2_P1.3mm_Open_Pad1.0x1.5mm
JP16, JP17: Closed; SolderJumper-2_P1.3mm_Bridged_RoundedPad1.0x1.5mm
N4, N5, N6, N7, N8: Cavalier_Alim; Manufacturer_Part_Number 15-29-1024
N11, N12: Connecteurs; Manufacturer_Part_Number 39503-2002
Q4, Q5: BSS119; SOT95P260X110-3N; Manufacturer_Part_Number BSS119NH6327XTSA1; not fitted
R26: 0R; R_0603_1608Metric_Pad0.98x0.95mm_HandSolder
R47, R49: 10k; R_0603_1608Metric_Pad0.98x0.95mm_HandSolder; Manufacturer_Part_Number 667-ERJ-3GEYJ103V; not fitted
R48, R50, R63: 10k; R_0603_1608Metric_Pad0.98x0.95mm_HandSolder; Manufacturer_Part_Number 667-ERJ-3GEYJ103V
R51, R52: 0.5R/0.1%; R_0603_1608Metric_Pad0.98x0.95mm_HandSolder; Manufacturer_Part_Number CSR0603FKR500
TH3: Thermistor_NTC; R_0603_1608Metric_Pad0.98x0.95mm_HandSolder; Manufacturer_Part_Number NCU18XH103E60RB
TP1: TX; TestPoint_Pad_D1.0mm
TP2: RX; TestPoint_Pad_D1.0mm
U6: L298N; TO-220-15_P2.54x5.08mm_StaggerOdd_Lead4.58mm_Vertical; Manufacturer_Part_Number L298N

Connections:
/MCU/3V3: R63.2; also elsewhere on the board
/MCU/SECONDARY_MOTOR0: JP9.1 (A); also elsewhere on the board
/MCU/SECONDARY_MOTOR1: JP10.1 (A); also elsewhere on the board
/MCU/SECONDARY_MOTOR2: U6.5 (IN1); also elsewhere on the board
/MCU/SECONDARY_MOTOR3: U6.7 (IN2); also elsewhere on the board
/MCU/SECONDARY_MOTOR4: U6.10 (IN3); also elsewhere on the board
/MCU/SECONDARY_MOTOR5: U6.12 (IN4); also elsewhere on the board
/MCU/SECONDARY_MOTOR6: U6.6 (EnA); also elsewhere on the board
/MCU/SECONDARY_MOTOR7: U6.11 (EnB); also elsewhere on the board
/MCU/SECONDARY_MOTOR8: R63.1, TH3.1; also elsewhere on the board
/MCU/SERVO0: JP17.1 (A), Q5.3; also elsewhere on the board
/MCU/SERVO1: JP16.1 (A), Q4.3; also elsewhere on the board
/MCU/SERVO2: IC9.1 (~1OE), IC9.7 (2OE), R48.1; also elsewhere on the board
/MCU/SERVO3: J24.3; also elsewhere on the board
/MCU/SERVO4: J26.3; also elsewhere on the board
/MCU/SERVO5: J28.3; also elsewhere on the board
/MCU/SERVO6: J33.3; also elsewhere on the board
/Motor/5V: C41.1, C108.1, J23.3, J25.3, J27.3, J29.3, J32.3, R26.1, U6.9 (Vss); also elsewhere on the board
/Motor/Motor_Actuators/5V_ROBOTIS: C105.1, IC9.8 (VCC), Q4.1, Q5.1, R26.2, R47.1, R49.1, R50.1
/Motor/Motor_Actuators/DATA: IC9.2 (1A), IC9.3 (2Y), J19.1, J20.1, J21.1, J22.1, R50.2
/Motor/Motor_Actuators/Motor1_High: D8.2 (A), D12.1 (K), J30.1, U6.2 (OUT1)
/Motor/Motor_Actuators/Motor1_Low: D9.2 (A), D13.1 (K), J30.2, U6.3 (OUT2)
/Motor/Motor_Actuators/Motor2_High: D10.2 (A), D14.1 (K), J31.1, U6.13 (OUT3)
/Motor/Motor_Actuators/Motor2_Low: D11.2 (A), D15.1 (K), J31.2, U6.14 (OUT4)
/Motor/Motor_Actuators/PWR_1: J24.2, J25.2
/Motor/Motor_Actuators/PWR_2: J26.2, J27.2
/Motor/Motor_Actuators/PWR_3: J28.2, J29.2
/Motor/Motor_Actuators/PWR_4: J32.2, J33.2
/Motor/Motor_Actuators/PWR_5: C109.1 (+), C111.1, C112.1, C113.1, C114.1, D8.1 (K), D9.1 (K), D10.1 (K), D11.1 (K), J23.2, U6.4 (Vs)
/Motor/Motor_Actuators/RX_UC_5V: IC9.6 (1Y), JP17.2 (B), Q5.2, R49.2, TP2.1
/Motor/Motor_Actuators/TX_UC_5V: IC9.5 (2A), JP16.2 (B), Q4.2, R47.2, TP1.1
/Power/12V: C40.1, C106.1, C107.1, C130.1, C131.1, J19.2, J20.2, J21.2, J22.2, J23.1, J25.1, J27.1, J29.1, J32.1; also elsewhere on the board
GND: C40.2, C41.2, C105.2, C106.2, C107.2, C108.2, C109.2 (-), C111.2, C112.2, C113.2, C114.2, C130.2, C131.2, D12.2 (A), D13.2 (A), D14.2 (A), D15.2 (A), H5.1, H5.2, IC9.4 (GND), J19.3, J20.3, J21.3, J22.3, J24.1, J26.1, J28.1, J33.1, R48.2, R51.2, R52.2, TH3.2, U6.8 (GND); also elsewhere on the board
unnamed: JP9.2 (B), R51.1, U6.1 (SENSE_A)
unnamed: JP10.2 (B), R52.1, U6.15 (SENSE_B)

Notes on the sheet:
D'après la doc: https://emanual.robotis.com/docs/en/dxl/ax/ax-12a/
Référence du radiateur Pas trouvé sur Mouser ou Digikey... https://www.ebay.fr/itm/201540333882
For ROBOTIS AX12 Servomotors
For Optional 2 DC motors
Level shifter 3V3 / 5V
For PWM Servomotors

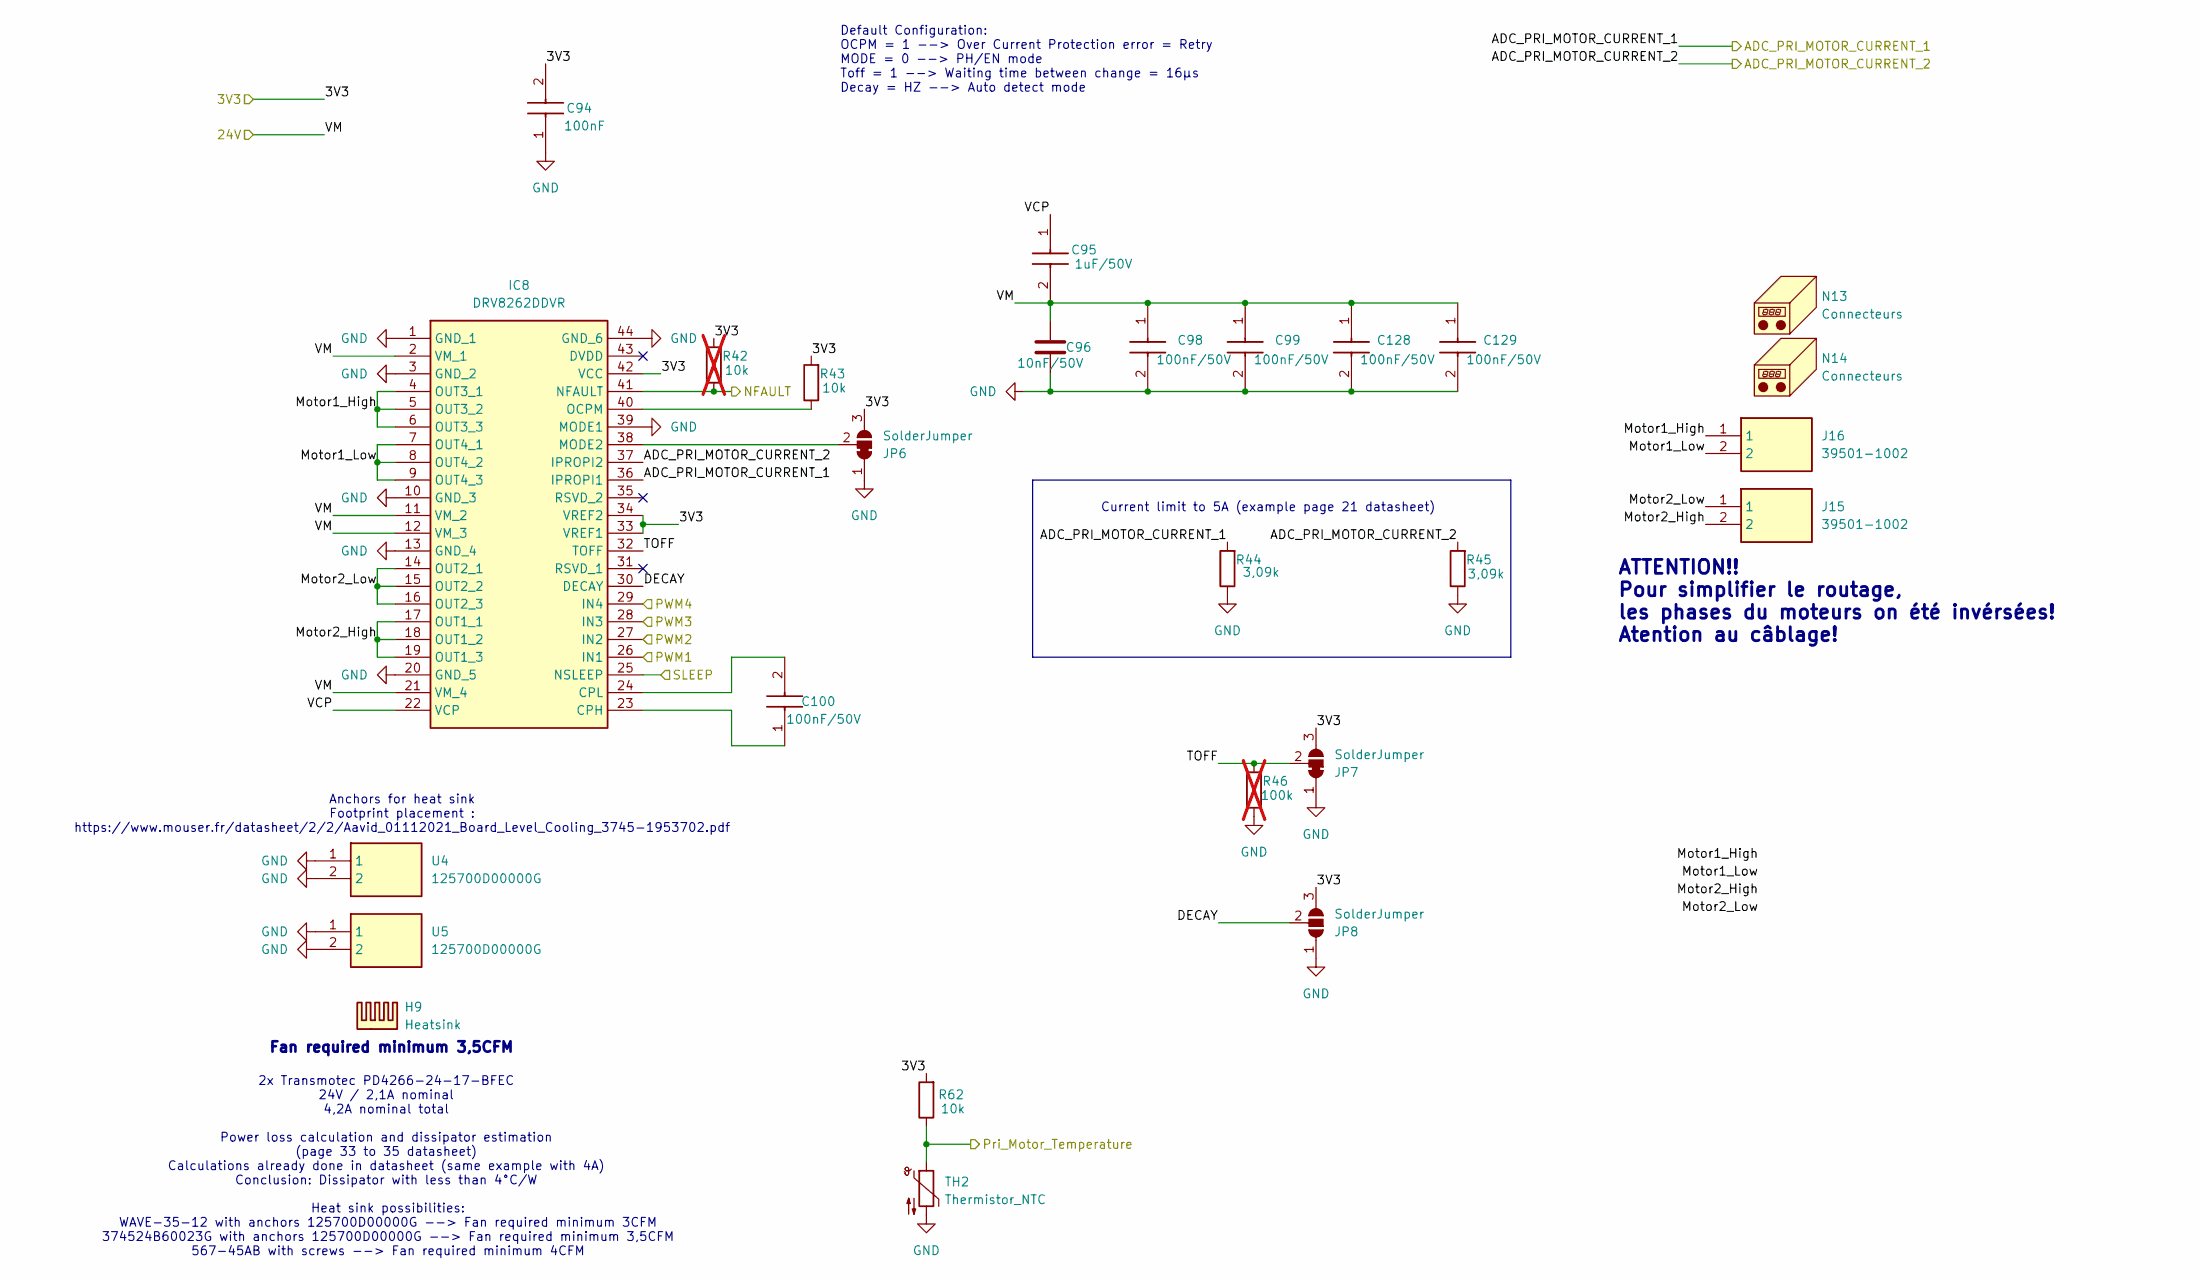
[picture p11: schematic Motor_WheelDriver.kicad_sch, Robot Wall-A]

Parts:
C94: 100nF; C_0603_1608Metric_Pad1.08x0.95mm_HandSolder; Manufacturer_Part_Number KGM15BR71H104KT
C95: 1uF/50V; C_0603_1608Metric_Pad1.08x0.95mm_HandSolder; Manufacturer_Part_Number CL10A105KB8NNNC
C96: 10nF/50V; C_0805_2012Metric_Pad1.18x1.45mm_HandSolder; Manufacturer_Part_Number CL21B103KBANNNC
C98, C99, C100, C128, C129: 100nF/50V; C_0603_1608Metric_Pad1.08x0.95mm_HandSolder; Manufacturer_Part_Number KGM15BR71H104KT
H9: Heatsink; 374524B60023G; Manufacturer_Part_Number 374524B60023G
IC8: DRV8262DDVR; SOP64P810X120-44N; Manufacturer_Part_Number DRV8262DDVR
J15, J16: 39501-1002; 395011002; Manufacturer_Part_Number 39501-1002
JP6, JP7: SolderJumper; SolderJumper-3_P1.3mm_Bridged12_Pad1.0x1.5mm
JP8: SolderJumper; SolderJumper-3_P1.3mm_Open_Pad1.0x1.5mm
N13, N14: Connecteurs; Manufacturer_Part_Number 39503-2002
R42: 10k; R_0603_1608Metric_Pad0.98x0.95mm_HandSolder; Manufacturer_Part_Number 667-ERJ-3GEYJ103V; not fitted
R43, R62: 10k; R_0603_1608Metric_Pad0.98x0.95mm_HandSolder; Manufacturer_Part_Number 667-ERJ-3GEYJ103V
R44, R45: 3,09k; R_0603_1608Metric_Pad0.98x0.95mm_HandSolder; Manufacturer_Part_Number CRCW06033K09FKEA
R46: 100k; R_0603_1608Metric_Pad0.98x0.95mm_HandSolder; Manufacturer_Part_Number RCA0603100KFKEAHP; not fitted
TH2: Thermistor_NTC; R_0603_1608Metric_Pad0.98x0.95mm_HandSolder; Manufacturer_Part_Number NCU18XH103E60RB
U4, U5: 125700D00000G; Manufacturer_Part_Number 125700D00000G

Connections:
/MCU/3V3: C94.2, IC8.33 (VREF1), IC8.34 (VREF2), IC8.42 (VCC), JP6.3 (B), JP7.3 (B), JP8.3 (B), R42.2, R43.2, R62.2; also elsewhere on the board
/MCU/WHEEL0: IC8.36 (IPROPI1), R44.2; also elsewhere on the board
/MCU/WHEEL1: IC8.37 (IPROPI2), R45.2; also elsewhere on the board
/MCU/WHEEL2: IC8.26 (IN1); also elsewhere on the board
/MCU/WHEEL3: IC8.27 (IN2); also elsewhere on the board
/MCU/WHEEL4: IC8.28 (IN3); also elsewhere on the board
/MCU/WHEEL5: IC8.29 (IN4); also elsewhere on the board
/MCU/WHEEL6: IC8.41 (NFAULT), R42.1; also elsewhere on the board
/MCU/WHEEL7: IC8.25 (NSLEEP); also elsewhere on the board
/MCU/WHEEL8: R62.1, TH2.1; also elsewhere on the board
/Motor/Motor_WheelDriver/DECAY: IC8.30 (DECAY), JP8.2 (C)
/Motor/Motor_WheelDriver/Motor1_High: IC8.4 (OUT3_1), IC8.5 (OUT3_2), IC8.6 (OUT3_3), J16.1
/Motor/Motor_WheelDriver/Motor1_Low: IC8.7 (OUT4_1), IC8.8 (OUT4_2), IC8.9 (OUT4_3), J16.2
/Motor/Motor_WheelDriver/Motor2_High: IC8.17 (OUT1_1), IC8.18 (OUT1_2), IC8.19 (OUT1_3), J15.2
/Motor/Motor_WheelDriver/Motor2_Low: IC8.14 (OUT2_1), IC8.15 (OUT2_2), IC8.16 (OUT2_3), J15.1
/Motor/Motor_WheelDriver/TOFF: IC8.32 (TOFF), JP7.2 (C), R46.2
/Motor/Motor_WheelDriver/VCP: C95.1, IC8.22 (VCP)
/Power/24V: C95.2, C96.1, C98.1, C99.1, C128.1, C129.1, IC8.2 (VM_1), IC8.11 (VM_2), IC8.12 (VM_3), IC8.21 (VM_4); also elsewhere on the board
GND: C94.1, C96.2, C98.2, C99.2, C128.2, C129.2, IC8.1 (GND_1), IC8.3 (GND_2), IC8.10 (GND_3), IC8.13 (GND_4), IC8.20 (GND_5), IC8.39 (MODE1), IC8.44 (GND_6), JP6.1 (A), JP7.1 (A), JP8.1 (A), R44.1, R45.1, R46.1, TH2.2, U4.1, U4.2, U5.1, U5.2; also elsewhere on the board
unnamed: C100.1, IC8.23 (CPH)
unnamed: C100.2, IC8.24 (CPL)
unnamed: IC8.38 (MODE2), JP6.2 (C)
unnamed: IC8.40 (OCPM), R43.1

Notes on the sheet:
Current limit to 5A (example page 21 datasheet)
Fan required minimum 3,5CFM
Power loss calculation and dissipator estimation (page 33 to 35 datasheet) Calculations already done in datasheet (same example with 4A) Conclusion: Dissipator with less than 4°C/W
Anchors for heat sink Footprint placement : https://www.mouser.fr/datasheet/2/2/Aavid_01112021_Board_Level_Cooling_3745-1953702.pdf
Default Configuration: OCPM = 1 --> Over Current Protection error = Retry MODE = 0 --> PH/EN mode Toff = 1 --> Waiting time between change = 16µs Decay = HZ --> Auto detect mode
ATTENTION!! Pour simplifier le routage, les phases du moteurs on été invérsées! Atention au câblage!
2x Transmotec PD4266-24-17-BFEC 24V / 2,1A nominal 4,2A nominal total
Heat sink possibilities: WAVE-35-12 with anchors 125700D00000G --> Fan required minimum 3CFM 374524B60023G with anchors 125700D00000G --> Fan required minimum 3,5CFM 567-45AB with screws --> Fan required minimum 4CFM

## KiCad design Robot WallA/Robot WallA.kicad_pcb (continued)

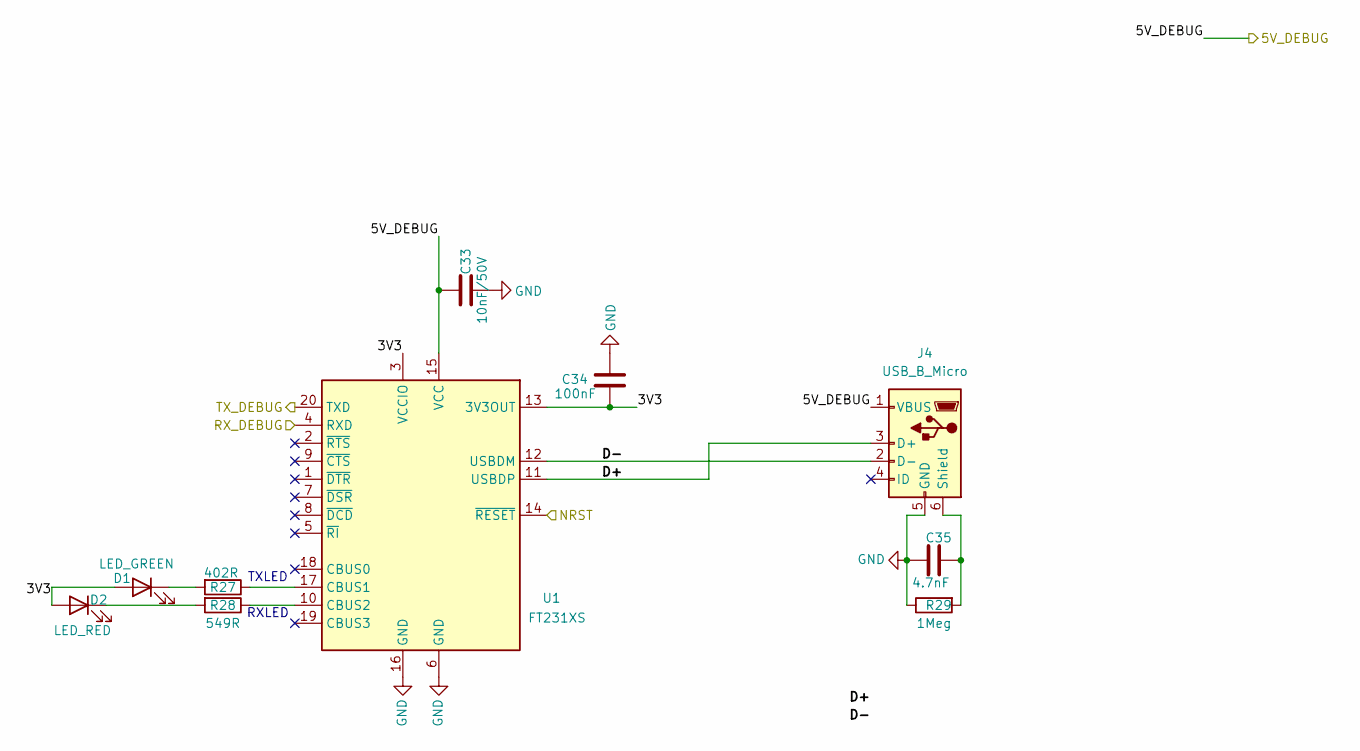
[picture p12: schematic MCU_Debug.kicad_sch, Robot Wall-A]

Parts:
C33: 10nF/50V; C_0805_2012Metric_Pad1.18x1.45mm_HandSolder; Manufacturer_Part_Number CL21B103KBANNNC
C34: 100nF; C_0603_1608Metric_Pad1.08x0.95mm_HandSolder; Manufacturer_Part_Number KGM15BR71H104KT
C35: 4.7nF; C_0603_1608Metric_Pad1.08x0.95mm_HandSolder; Manufacturer_Part_Number CC0603JRX7R8BB472
D1: LED_GREEN; LED_0603_1608Metric; Manufacturer_Part_Number APT1608LZGCK
D2: LED_RED; LED_0603_1608Metric; Manufacturer_Part_Number LS L29K-G1J2-1
J4: USB_B_Micro; USB_Micro-B_Molex_47346-0001; Manufacturer_Part_Number USB3140-30-0230-0-C
R27: 402R; R_0603_1608Metric_Pad0.98x0.95mm_HandSolder; Manufacturer_Part_Number CR0603-FX-4020ELF
R28: 549R; R_0603_1608Metric_Pad0.98x0.95mm_HandSolder; Manufacturer_Part_Number RC0603FR-07549RL
R29: 1Meg; R_0603_1608Metric_Pad0.98x0.95mm_HandSolder; Manufacturer_Part_Number ERJ-3GEYJ105V
U1: FT231XS; SSOP-20_3.9x8.7mm_P0.635mm; Manufacturer_Part_Number FT231XS-R

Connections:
/MCU/MCU_Core/NRST: U1.14 (~RESET); also elsewhere on the board
/MCU/MCU_Core/PA9: U1.4 (RXD); also elsewhere on the board
/MCU/MCU_Core/PA10: U1.20 (TXD); also elsewhere on the board
/MCU/MCU_Debug/3V3: C34.1, D1.2 (A), D2.2 (A), U1.3 (VCCIO), U1.13 (3V3OUT)
/MCU/MCU_Debug/5V_DEBUG: C33.1, J4.1 (VBUS), U1.15 (VCC); also elsewhere on the board
/MCU/MCU_Debug/D+: J4.3 (D+), U1.11 (USBDP)
/MCU/MCU_Debug/D-: J4.2 (D-), U1.12 (USBDM)
GND: C33.2, C34.2, C35.2, J4.5 (GND), R29.1, U1.6 (GND), U1.16 (GND); also elsewhere on the board
unnamed: D1.1 (K), R27.2
unnamed: D2.1 (K), R28.2
unnamed: C35.1, J4.6 (Shield), R29.2
unnamed: R27.1, U1.17 (CBUS1)
unnamed: R28.1, U1.10 (CBUS2)

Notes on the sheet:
TXLED
RXLED

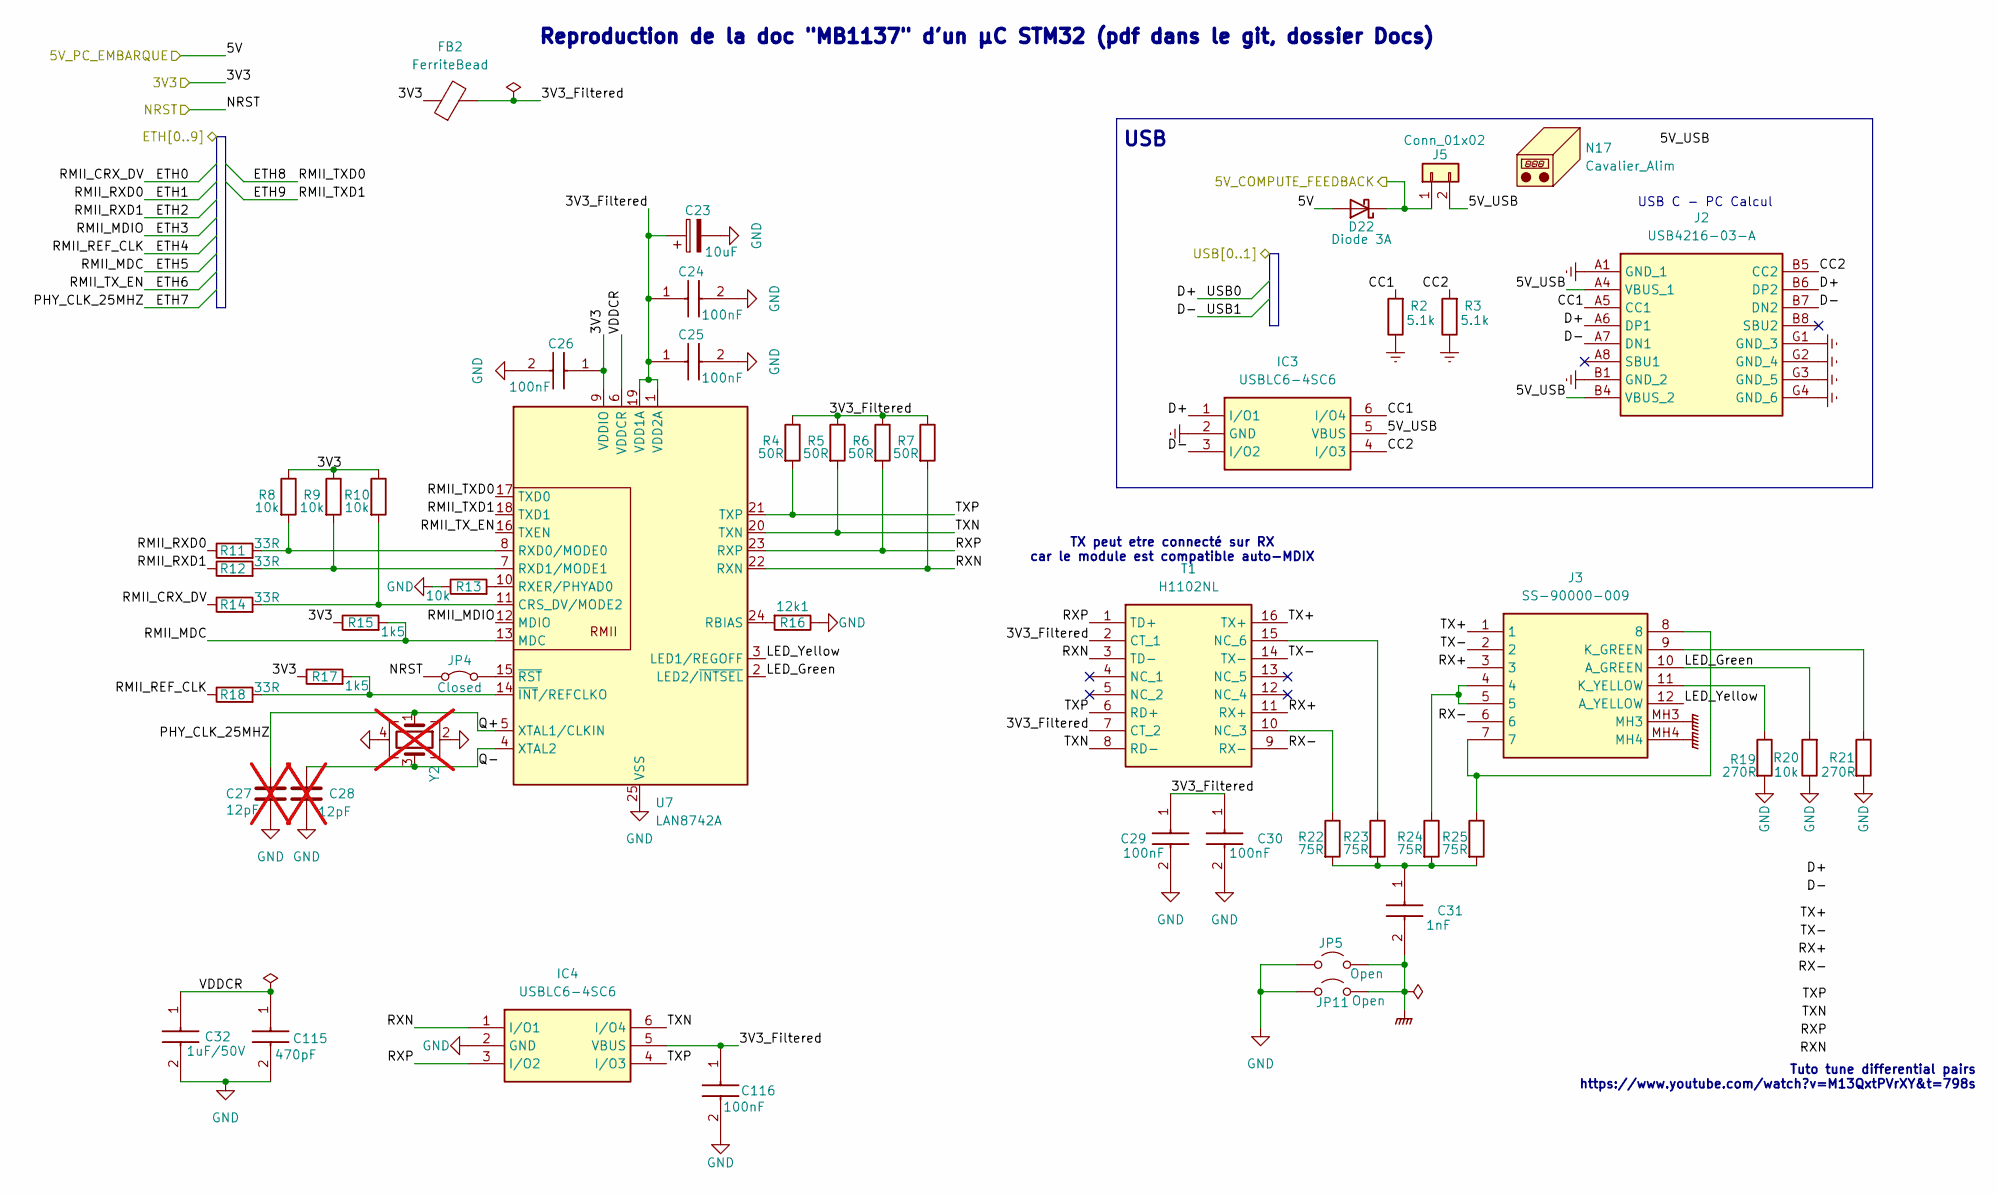
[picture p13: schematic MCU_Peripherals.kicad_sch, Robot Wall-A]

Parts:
C23: 10uF; C_1206_3216Metric_Pad1.33x1.80mm_HandSolder; Manufacturer_Part_Number CL31A106KQHNNNE
C24, C25, C26, C29, C30, C116: 100nF; C_0603_1608Metric_Pad1.08x0.95mm_HandSolder; Manufacturer_Part_Number KGM15BR71H104KT
C27, C28: 12pF; C_0603_1608Metric_Pad1.08x0.95mm_HandSolder; Manufacturer_Part_Number C0603C120F5GACTU; not fitted
C31: 1nF; C_1206_3216Metric_Pad1.33x1.80mm_HandSolder; Manufacturer_Part_Number 1206B102K102CT
C32: 1uF/50V; C_0603_1608Metric_Pad1.08x0.95mm_HandSolder; Manufacturer_Part_Number CL10A105KB8NNNC
C115: 470pF; C_0603_1608Metric_Pad1.08x0.95mm_HandSolder; Manufacturer_Part_Number C0603C471K5RACTU
D22: Diode 3A; D_SMP_DO-220AA; Manufacturer_Part_Number SS3P4-M3/84A
FB2: FerriteBead; R_0603_1608Metric_Pad0.98x0.95mm_HandSolder; Manufacturer_Part_Number FCM 1608KF-601T03
IC3, IC4: USBLC6-4SC6; SOT95P280X145-6N; Manufacturer_Part_Number USBLC6-4SC6
J2: USB4216-03-A; USB421603A; Manufacturer_Part_Number USB4216-03-A
J3: SS-90000-009; SS90000009; Manufacturer_Part_Number SS-90000-009
J5: Conn_01x02; PinHeader_1x02_P2.54mm_Vertical
JP4: Closed; SolderJumper-2_P1.3mm_Bridged_RoundedPad1.0x1.5mm
JP5, JP11: Open; SolderJumper-2_P1.3mm_Open_RoundedPad1.0x1.5mm
N17: Cavalier_Alim; Manufacturer_Part_Number 15-29-1024
R2, R3: 5.1k; R_0603_1608Metric_Pad0.98x0.95mm_HandSolder; Manufacturer_Part_Number CRCW06035K10FKEA
R4, R5, R6, R7: 50R; R_0603_1608Metric; Manufacturer_Part_Number CRCW060350R0FKTA
R8, R9, R10, R13, R20: 10k; R_0603_1608Metric_Pad0.98x0.95mm_HandSolder; Manufacturer_Part_Number 667-ERJ-3GEYJ103V
R11, R12, R14, R18: 33R; R_0603_1608Metric_Pad0.98x0.95mm_HandSolder; Manufacturer_Part_Number CRCW060333R0JNEA
R15, R17: 1k5; R_0603_1608Metric_Pad0.98x0.95mm_HandSolder; Manufacturer_Part_Number RC0603JR-071K5L
R16: 12k1; R_0603_1608Metric_Pad0.98x0.95mm_HandSolder; Manufacturer_Part_Number ERJ-3EKF1212V
R19, R21: 270R; R_0603_1608Metric_Pad0.98x0.95mm_HandSolder; Manufacturer_Part_Number RE0603FRE07270RL
R22, R23, R24, R25: 75R; R_0603_1608Metric_Pad0.98x0.95mm_HandSolder; Manufacturer_Part_Number CRCW060375R0FKEAC
T1: H1102NL; SOIC127P940X597-16N; Manufacturer_Part_Number H1102NL
U7: LAN8742A; QFN50P400X400X100-25N-D; Manufacturer_Part_Number LAN8742A-CZ
Y2: Crystal_GND24; Crystal_SMD_3225-4Pin_3.2x2.5mm; Manufacturer_Part_Number ECS-250-10-33B-CWN-TR3; not fitted

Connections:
/MCU/3V3: C26.1, FB2.1, R8.1, R9.1, R10.1, R15.1, R17.1, U7.9 (VDDIO); also elsewhere on the board
/MCU/5V_PC_EMBARQUE: D22.2 (A); also elsewhere on the board
/MCU/MCU_Core/ETH0: R14.1; also elsewhere on the board
/MCU/MCU_Core/ETH1: R11.1; also elsewhere on the board
/MCU/MCU_Core/ETH2: R12.1; also elsewhere on the board
/MCU/MCU_Core/ETH3: U7.12 (MDIO); also elsewhere on the board
/MCU/MCU_Core/ETH4: R18.1; also elsewhere on the board
/MCU/MCU_Core/ETH5: R15.2, U7.13 (MDC); also elsewhere on the board
/MCU/MCU_Core/ETH6: U7.16 (TXEN); also elsewhere on the board
/MCU/MCU_Core/ETH7: C27.1, U7.5 (XTAL1/CLKIN), Y2.1; also elsewhere on the board
/MCU/MCU_Core/ETH8: U7.17 (TXD0); also elsewhere on the board
/MCU/MCU_Core/ETH9: U7.18 (TXD1); also elsewhere on the board
/MCU/MCU_Core/NRST: JP4.1 (A); also elsewhere on the board
/MCU/MCU_Core/USB0: IC3.1 (I/O1), J2.A6 (DP1), J2.B6 (DP2); also elsewhere on the board
/MCU/MCU_Core/USB1: IC3.3 (I/O2), J2.A7 (DN1), J2.B7 (DN2); also elsewhere on the board
/MCU/MCU_Peripherals/3V3_Filtered: C23.1, C24.1, C25.1, C29.1, C30.1, C116.1, FB2.2, IC4.5 (VBUS), R4.1, R5.1, R6.1, R7.1, T1.2 (CT_1), T1.7 (CT_2), U7.1 (VDD2A), U7.19 (VDD1A)
/MCU/MCU_Peripherals/5V_USB: IC3.5 (VBUS), J2.A4 (VBUS_1), J2.B4 (VBUS_2), J5.2
/MCU/MCU_Peripherals/CC1: IC3.6 (I/O4), J2.A5 (CC1), R2.2
/MCU/MCU_Peripherals/CC2: IC3.4 (I/O3), J2.B5 (CC2), R3.2
/MCU/MCU_Peripherals/LED_Green: J3.10 (A_GREEN), R20.2, U7.2 (LED2/~INTSEL)
/MCU/MCU_Peripherals/LED_Yellow: J3.12 (A_YELLOW), U7.3 (LED1/REGOFF)
/MCU/MCU_Peripherals/Q-: C28.1, U7.4 (XTAL2), Y2.3
/MCU/MCU_Peripherals/RX+: J3.3, T1.11 (RX+)
/MCU/MCU_Peripherals/RX-: J3.6, T1.9 (RX-)
/MCU/MCU_Peripherals/RXN: IC4.1 (I/O1), R7.2, T1.3 (TD-), U7.22 (RXN)
/MCU/MCU_Peripherals/RXP: IC4.3 (I/O2), R6.2, T1.1 (TD+), U7.23 (RXP)
/MCU/MCU_Peripherals/TX+: J3.1, T1.16 (TX+)
/MCU/MCU_Peripherals/TX-: J3.2, T1.14 (TX-)
/MCU/MCU_Peripherals/TXN: IC4.6 (I/O4), R5.2, T1.8 (RD-), U7.20 (TXN)
/MCU/MCU_Peripherals/TXP: IC4.4 (I/O3), R4.2, T1.6 (RD+), U7.21 (TXP)
/MCU/MCU_Peripherals/VDDCR: C32.1, C115.1, U7.6 (VDDCR)
/Power/Power_Buck_5V_Compute/5V_sense: D22.1 (K), J5.1; also elsewhere on the board
GND: C23.2, C24.2, C25.2, C26.2, C27.2, C28.2, C29.2, C30.2, C32.2, C115.2, C116.2, IC3.2 (GND), IC4.2 (GND), J2.A1 (GND_1), J2.B1 (GND_2), J2.G1 (GND_3), J2.G2 (GND_4), J2.G3 (GND_5), J2.G4 (GND_6), JP5.2 (B), JP11.2 (B), R2.1, R3.1, R13.1, R16.1, R19.2, R20.1, R21.2, U7.25 (VSS), Y2.2, Y2.4; also elsewhere on the board
GNDPWR: C31.2, J3.MH3, J3.MH4, JP5.1 (A), JP11.1 (A)
unnamed: C31.1, R22.2, R23.2, R24.2, R25.2
unnamed: J3.9 (K_GREEN), R21.1
unnamed: J3.11 (K_YELLOW), R19.1
unnamed: J3.4, J3.5, R24.1
unnamed: J3.7, J3.8, R25.1
unnamed: JP4.2 (B), U7.15 (~RST)
unnamed: R22.1, T1.10 (NC_3)
unnamed: R23.1, T1.15 (NC_6)
unnamed: R10.2, R14.2, U7.11 (CRS_DV/MODE2)
unnamed: R16.2, U7.24 (RBIAS)
unnamed: R8.2, R11.2, U7.8 (RXD0/MODE0)
unnamed: R9.2, R12.2, U7.7 (RXD1/MODE1)
unnamed: R13.2, U7.10 (RXER/PHYAD0)
unnamed: R17.2, R18.2, U7.14 (~INT/REFCLKO)

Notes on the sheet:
USB C - PC Calcul
TX peut etre connecté sur RX car le module est compatible auto-MDIX
Reproduction de la doc "MB1137" d'un µC STM32 (pdf dans le git, dossier Docs)
Tuto tune differential pairs https://www.youtube.com/watch?v=M13QxtPVrXY&t=798s
USB

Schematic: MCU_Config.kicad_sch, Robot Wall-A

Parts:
C3: 4.7uF/50V; C_0805_2012Metric_Pad1.18x1.45mm_HandSolder; Manufacturer_Part_Number GRM21BR61H475ME51L
C4, C5, C6, C7, C8, C9, C10, C11, C12, C13, C14, C15, C16, C17, C18, C19, C22: 100nF; C_0603_1608Metric_Pad1.08x0.95mm_HandSolder; Manufacturer_Part_Number KGM15BR71H104KT
C20, C21: 2.2uF; C_0603_1608Metric_Pad1.08x0.95mm_HandSolder; Manufacturer_Part_Number TMK107ABJ225KA-T
FB1: Bead 600R; R_0603_1608Metric_Pad0.98x0.95mm_HandSolder; Manufacturer_Part_Number FCM 1608KF-601T03
JP1, JP2, JP3: SolderJumper; SolderJumper-3_P1.3mm_Bridged12_Pad1.0x1.5mm
R1: 10k; R_0603_1608Metric_Pad0.98x0.95mm_HandSolder; Manufacturer_Part_Number 667-ERJ-3GEYJ103V; not fitted
SW1: Switch; KMR231NGLFS; Manufacturer_Part_Number KMR231NGLFS

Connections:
/MCU/3V3: C3.1, C4.1, C5.1, C6.1, C7.1, C8.1, C9.1, C10.1, C11.1, C12.1, C13.1, C14.1, C15.1, C16.1, C17.1, C18.1, FB1.1, JP1.3 (B), JP2.3 (B), JP3.1 (A), R1.2; also elsewhere on the board
/MCU/MCU_Config/3V3_ANA: C19.1, FB1.2; also elsewhere on the board
/MCU/MCU_Config/BOOT0: JP1.2 (C); also elsewhere on the board
/MCU/MCU_Config/BYPASS_REG: JP2.2 (C); also elsewhere on the board
/MCU/MCU_Config/PDR_ON: JP3.2 (C); also elsewhere on the board
/MCU/MCU_Config/VCAP_1: C20.1; also elsewhere on the board
/MCU/MCU_Config/VCAP_2: C21.1; also elsewhere on the board
/MCU/MCU_Core/NRST: C22.2, R1.1, SW1.2 (D); also elsewhere on the board
GND: C3.2, C4.2, C5.2, C6.2, C7.2, C8.2, C9.2, C10.2, C11.2, C12.2, C13.2, C14.2, C15.2, C16.2, C17.2, C18.2, C19.2, C20.2, C21.2, C22.1, JP1.1 (A), JP2.1 (A), JP3.3 (B), SW1.1 (C); also elsewhere on the board

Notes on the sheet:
Must be as close as possible from µC

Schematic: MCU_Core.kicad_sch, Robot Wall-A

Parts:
C1, C2: 12pF; C_0603_1608Metric_Pad1.08x0.95mm_HandSolder; Manufacturer_Part_Number C0603C120F5GACTU
D17: LED_YELLOW; LED_0603_1608Metric; Manufacturer_Part_Number SML-D12W8WT86C
D18: LED_ORANGE; LED_0603_1608Metric; Manufacturer_Part_Number CSL1901DW1
D19: LED_GREEN; LED_0603_1608Metric; Manufacturer_Part_Number APT1608LZGCK
D20: LED_BLUE; LED_0603_1608Metric; Manufacturer_Part_Number APT1608LVBC/D
D21: LED_RED; LED_0603_1608Metric; Manufacturer_Part_Number LS L29K-G1J2-1
IC1: STM32F407IGT6; QFP50P2600X2600X160-176N; Manufacturer_Part_Number STM32F407IGT6
IC2: DS04-254-2-04BK-SMT; SOP254P990X430-8N; Manufacturer_Part_Number DS04-254-2-04BK-SMT
J1: Conn_02x05_Female; PinHeader_2x05_P1.27mm_Vertical
R55: 649R; R_0603_1608Metric_Pad0.98x0.95mm_HandSolder; Manufacturer_Part_Number RC0603FR-07649RL
R56: 750R; R_0603_1608Metric_Pad0.98x0.95mm_HandSolder; Manufacturer_Part_Number RC0603FR-10750RL
R57: 324R; R_0603_1608Metric_Pad0.98x0.95mm_HandSolder; Manufacturer_Part_Number RC0603FR-07324RL
R58: 330R; R_0603_1608Metric_Pad0.98x0.95mm_HandSolder; Manufacturer_Part_Number AF0603JR-07330RL
R59: 549R; R_0603_1608Metric_Pad0.98x0.95mm_HandSolder; Manufacturer_Part_Number RC0603FR-07549RL
Y1: Crystal_GND24; Crystal_SMD_3225-4Pin_3.2x2.5mm; Manufacturer_Part_Number ECS-250-10-33B-CWN-TR3

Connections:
/MCU/3V3: D17.2 (A), D18.2 (A), D19.2 (A), D20.2 (A), D21.2 (A), IC1.6 (VBAT), IC1.15 (VDD_1), IC1.23 (VDD_2), IC1.36 (VDD_3), IC1.49 (VDD_4), IC1.62 (VDD_5), IC1.72 (VDD_6), IC1.82 (VDD_7), IC1.91 (VDD_8), IC1.103 (VDD_9), IC1.114 (VDD_10), IC1.127 (VDD_11), IC1.136 (VDD_12), IC1.149 (VDD_13), IC1.159 (VDD_14), IC1.172 (VDD_15), J1.1; also elsewhere on the board
/MCU/ENCODER0: IC1.116 (PC7); also elsewhere on the board
/MCU/ENCODER1: IC1.115 (PC6); also elsewhere on the board
/MCU/ENCODER2: IC1.101 (PD13); also elsewhere on the board
/MCU/ENCODER3: IC1.100 (PD12); also elsewhere on the board
/MCU/MCU_Config/3V3_ANA: IC1.38 (VREF+), IC1.39 (VDDA); also elsewhere on the board
/MCU/MCU_Config/BOOT0: IC1.166 (BOOT0); also elsewhere on the board
/MCU/MCU_Config/BYPASS_REG: IC1.48 (BYPASS_REG); also elsewhere on the board
/MCU/MCU_Config/PDR_ON: IC1.171 (PDR_ON); also elsewhere on the board
/MCU/MCU_Config/VCAP_1: IC1.81 (VCAP_1); also elsewhere on the board
/MCU/MCU_Config/VCAP_2: IC1.125 (VCAP_2); also elsewhere on the board
/MCU/MCU_Core/ETH0: IC1.53 (PA7); also elsewhere on the board
/MCU/MCU_Core/ETH1: IC1.54 (PC4); also elsewhere on the board
/MCU/MCU_Core/ETH2: IC1.55 (PC5); also elsewhere on the board
/MCU/MCU_Core/ETH3: IC1.42 (PA2); also elsewhere on the board
/MCU/MCU_Core/ETH4: IC1.41 (PA1); also elsewhere on the board
/MCU/MCU_Core/ETH5: IC1.33 (PC1); also elsewhere on the board
/MCU/MCU_Core/ETH6: IC1.154 (PG11); also elsewhere on the board
/MCU/MCU_Core/ETH7: IC1.119 (PA8); also elsewhere on the board
/MCU/MCU_Core/ETH8: IC1.92 (PB12); also elsewhere on the board
/MCU/MCU_Core/ETH9: IC1.93 (PB13); also elsewhere on the board
/MCU/MCU_Core/LED_Blue: IC1.4 (PE5), R58.1
/MCU/MCU_Core/LED_Green: IC1.3 (PE4), R57.1
/MCU/MCU_Core/LED_Orange: IC1.1 (PE2), R56.1
/MCU/MCU_Core/LED_Red: IC1.5 (PE6), R59.1
/MCU/MCU_Core/LED_Yellow: IC1.2 (PE3), R55.2
/MCU/MCU_Core/NRST: IC1.31 (NRST), J1.10; also elsewhere on the board
/MCU/MCU_Core/PA0: IC1.40 (PA0); also elsewhere on the board
/MCU/MCU_Core/PA9: IC1.120 (PA9); also elsewhere on the board
/MCU/MCU_Core/PA10: IC1.121 (PA10); also elsewhere on the board
/MCU/MCU_Core/PB6: IC1.164 (PB6); also elsewhere on the board
/MCU/MCU_Core/PB7: IC1.165 (PB7); also elsewhere on the board
/MCU/MCU_Core/PB8: IC1.167 (PB8); also elsewhere on the board
/MCU/MCU_Core/PB9: IC1.168 (PB9); also elsewhere on the board
/MCU/MCU_Core/PD0: IC1.142 (PD0); also elsewhere on the board
/MCU/MCU_Core/PD4: IC1.146 (PD4); also elsewhere on the board
/MCU/MCU_Core/PD7: IC1.151 (PD7); also elsewhere on the board
/MCU/MCU_Core/PE0: IC1.169 (PE0); also elsewhere on the board
/MCU/MCU_Core/PE8: IC1.69 (PE8); also elsewhere on the board
/MCU/MCU_Core/PE12: IC1.75 (PE12); also elsewhere on the board
/MCU/MCU_Core/PF3: IC1.19 (PF3); also elsewhere on the board
/MCU/MCU_Core/PF4: IC1.20 (PF4); also elsewhere on the board
/MCU/MCU_Core/PF5: IC1.21 (PF5); also elsewhere on the board
/MCU/MCU_Core/PF9: IC1.27 (PF9); also elsewhere on the board
/MCU/MCU_Core/PF10: IC1.28 (PF10); also elsewhere on the board
/MCU/MCU_Core/PG7: IC1.111 (PG7); also elsewhere on the board
/MCU/MCU_Core/PG8: IC1.112 (PG8); also elsewhere on the board
/MCU/MCU_Core/PG9: IC1.152 (PG9); also elsewhere on the board
/MCU/MCU_Core/PG12: IC1.155 (PG12); also elsewhere on the board
/MCU/MCU_Core/PG14: IC1.157 (PG14); also elsewhere on the board
/MCU/MCU_Core/PG15: IC1.160 (PG15); also elsewhere on the board
/MCU/MCU_Core/PH13: IC1.128 (PH13); also elsewhere on the board
/MCU/MCU_Core/PI1: IC1.132 (PI1); also elsewhere on the board
/MCU/MCU_Core/PI2: IC1.133 (PI2); also elsewhere on the board
/MCU/MCU_Core/PI3: IC1.134 (PI3); also elsewhere on the board
/MCU/MCU_Core/SWCLK: IC1.137 (PA14), J1.4
/MCU/MCU_Core/SWDIO: IC1.124 (PA13), J1.2
/MCU/MCU_Core/USB0: IC1.123 (PA12); also elsewhere on the board
/MCU/MCU_Core/USB1: IC1.122 (PA11); also elsewhere on the board
/MCU/MCU_Core/UserSwitch_1: IC1.10 (PC15), IC2.5 (NO_1)
/MCU/MCU_Core/UserSwitch_2: IC1.11 (PI9), IC2.6 (NO_2)
/MCU/MCU_Core/UserSwitch_3: IC1.12 (PI10), IC2.7 (NO_3)
/MCU/MCU_Core/UserSwitch_4: IC1.13 (PI11), IC2.8 (NO_4)
/MCU/SECONDARY_MOTOR0: IC1.52 (PA6); also elsewhere on the board
/MCU/SECONDARY_MOTOR1: IC1.56 (PB0); also elsewhere on the board
/MCU/SECONDARY_MOTOR2: IC1.107 (PG3); also elsewhere on the board
/MCU/SECONDARY_MOTOR3: IC1.108 (PG4); also elsewhere on the board
/MCU/SECONDARY_MOTOR4: IC1.109 (PG5); also elsewhere on the board
/MCU/SECONDARY_MOTOR5: IC1.110 (PG6); also elsewhere on the board
/MCU/SECONDARY_MOTOR6: IC1.87 (PH10); also elsewhere on the board
/MCU/SECONDARY_MOTOR7: IC1.88 (PH11); also elsewhere on the board
/MCU/SECONDARY_MOTOR8: IC1.25 (PF7); also elsewhere on the board
/MCU/SENSORS0: IC1.34 (PC2); also elsewhere on the board
/MCU/SENSORS1: IC1.32 (PC0); also elsewhere on the board
/MCU/SENSORS2: IC1.35 (PC3); also elsewhere on the board
/MCU/SENSORS3: IC1.57 (PB1); also elsewhere on the board
/MCU/SENSORS4: IC1.65 (PF15); also elsewhere on the board
/MCU/SENSORS5: IC1.66 (PG0); also elsewhere on the board
/MCU/SENSORS6: IC1.64 (PF14); also elsewhere on the board
/MCU/SENSORS7: IC1.67 (PG1); also elsewhere on the board
/MCU/SENSORS8: IC1.162 (PB4); also elsewhere on the board
/MCU/SENSORS9: IC1.117 (PC8); also elsewhere on the board
/MCU/SENSORS10: IC1.163 (PB5); also elsewhere on the board
/MCU/SENSORS11: IC1.118 (PC9); also elsewhere on the board
/MCU/SENSORS12: IC1.63 (PF13); also elsewhere on the board
/MCU/SENSORS13: IC1.60 (PF12); also elsewhere on the board
/MCU/SENSORS14: IC1.59 (PF11); also elsewhere on the board
/MCU/SENSORS15: IC1.58 (PB2); also elsewhere on the board
/MCU/SERVO0: IC1.150 (PD6); also elsewhere on the board
/MCU/SERVO1: IC1.147 (PD5); also elsewhere on the board
/MCU/SERVO2: IC1.176 (PI7); also elsewhere on the board
/MCU/SERVO3: IC1.51 (PA5); also elsewhere on the board
/MCU/SERVO4: IC1.161 (PB3); also elsewhere on the board
/MCU/SERVO5: IC1.79 (PB10); also elsewhere on the board
/MCU/SERVO6: IC1.80 (PB11); also elsewhere on the board
/MCU/WHEEL0: IC1.47 (PA3); also elsewhere on the board
/MCU/WHEEL1: IC1.50 (PA4); also elsewhere on the board
/MCU/WHEEL2: IC1.70 (PE9); also elsewhere on the board
/MCU/WHEEL3: IC1.74 (PE11); also elsewhere on the board
/MCU/WHEEL4: IC1.76 (PE13); also elsewhere on the board
/MCU/WHEEL5: IC1.77 (PE14); also elsewhere on the board
/MCU/WHEEL6: IC1.18 (PF2); also elsewhere on the board
/MCU/WHEEL7: IC1.17 (PF1); also elsewhere on the board
/MCU/WHEEL8: IC1.24 (PF6); also elsewhere on the board
/Power/GPIO_ENABLE_POWER_SUPPLIES: IC1.95 (PB15); also elsewhere on the board
/Power/GPIO_PGOOD: IC1.94 (PB14); also elsewhere on the board
/Power/Temperature: IC1.26 (PF8); also elsewhere on the board
GND: C1.2, C2.2, IC1.14 (VSS_1), IC1.22 (VSS_2), IC1.37 (VSSA), IC1.61 (VSS_3), IC1.71 (VSS_4), IC1.90 (VSS_5), IC1.102 (VSS_6), IC1.113 (VSS_7), IC1.126 (VSS_8), IC1.135 (VSS_9), IC1.148 (VSS_10), IC1.158 (VSS_11), IC2.1 (COM_1), IC2.2 (COM_2), IC2.3 (COM_3), IC2.4 (COM_4), J1.3, J1.5, Y1.2, Y1.4; also elsewhere on the board
unnamed: D17.1 (K), R55.1
unnamed: D18.1 (K), R56.2
unnamed: D19.1 (K), R57.2
unnamed: D20.1 (K), R58.2
unnamed: D21.1 (K), R59.2
unnamed: C1.1, IC1.29 (PH0), Y1.1
unnamed: C2.1, IC1.30 (PH1), Y1.3

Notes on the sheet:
Program
USB --> PC CALCUL ETHERNET --> PC CALCUL UART1 --> DEBUG UART2 --> SERVOMOTEURS
Pour calculer la valeurs des condo autour du Quartz: Application note an2867 page 13
USER INTERFACE
DEBUG LEDs

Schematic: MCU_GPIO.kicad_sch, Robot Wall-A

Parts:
J6, J13: 10129383-916001ALF; 10129383916001ALF; Manufacturer_Part_Number 10129383-916001ALF

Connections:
/MCU/3V3: J6.A1, J6.B1; also elsewhere on the board
/MCU/MCU_Core/PA0: J6.A8; also elsewhere on the board
/MCU/MCU_Core/PA9: J6.A5; also elsewhere on the board
/MCU/MCU_Core/PA10: J6.B5; also elsewhere on the board
/MCU/MCU_Core/PB6: J13.B6; also elsewhere on the board
/MCU/MCU_Core/PB7: J13.A6; also elsewhere on the board
/MCU/MCU_Core/PB8: J13.B7; also elsewhere on the board
/MCU/MCU_Core/PB9: J13.A7; also elsewhere on the board
/MCU/MCU_Core/PD0: J13.B2; also elsewhere on the board
/MCU/MCU_Core/PD4: J13.B3; also elsewhere on the board
/MCU/MCU_Core/PD7: J13.A3; also elsewhere on the board
/MCU/MCU_Core/PE0: J13.B8; also elsewhere on the board
/MCU/MCU_Core/PE8: J6.B4; also elsewhere on the board
/MCU/MCU_Core/PE12: J6.A4; also elsewhere on the board
/MCU/MCU_Core/PF3: J13.A8; also elsewhere on the board
/MCU/MCU_Core/PF4: J6.B7; also elsewhere on the board
/MCU/MCU_Core/PF5: J6.B8; also elsewhere on the board
/MCU/MCU_Core/PF9: J6.A6; also elsewhere on the board
/MCU/MCU_Core/PF10: J6.A7; also elsewhere on the board
/MCU/MCU_Core/PG7: J6.A3; also elsewhere on the board
/MCU/MCU_Core/PG8: J6.B3; also elsewhere on the board
/MCU/MCU_Core/PG9: J13.B4; also elsewhere on the board
/MCU/MCU_Core/PG12: J13.A4; also elsewhere on the board
/MCU/MCU_Core/PG14: J13.B5; also elsewhere on the board
/MCU/MCU_Core/PG15: J13.A5; also elsewhere on the board
/MCU/MCU_Core/PH13: J6.B6; also elsewhere on the board
/MCU/MCU_Core/PI1: J13.A1; also elsewhere on the board
/MCU/MCU_Core/PI2: J13.A2; also elsewhere on the board
/MCU/MCU_Core/PI3: J13.B1; also elsewhere on the board
GND: J6.A2, J6.B2; also elsewhere on the board

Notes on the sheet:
DEBUG UART RX -> PA10 TX -> PA9 I2C1 SDA -> PB7 SCL -> PB6 SPI2 MISO -> PI2 MOSI -> PI3 SCK -> PI1 UART6 RX -> PG9 TX -> PG14 CAN1 RX -> PD0 TX ->PH13

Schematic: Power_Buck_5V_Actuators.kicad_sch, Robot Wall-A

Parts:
C86: 100uF; CAPPRD350W65D800H1250; Manufacturer_Part_Number EEU-FC1V101
C87, C118, C124, C125: 4.7uF/50V; C_1210_3225Metric_Pad1.33x2.70mm_HandSolder; Manufacturer_Part_Number GRM32ER71H475KA88L
C119: 10nF/50V; C_0805_2012Metric_Pad1.18x1.45mm_HandSolder; Manufacturer_Part_Number CL21B103KBANNNC
C120: 2.2uF/50V; C_1210_3225Metric_Pad1.33x2.70mm_HandSolder; Manufacturer_Part_Number C3225X7R1H225K250AB
C121, C122, C123: 47nF/50V; C_0603_1608Metric_Pad1.08x0.95mm_HandSolder; Manufacturer_Part_Number CC0603KPX7R9BB473
D5: LED_RED; LED_0603_1608Metric; Manufacturer_Part_Number LS L29K-G1J2-1
JP12: Closed; SolderJumper-2_P1.3mm_Bridged_RoundedPad1.0x1.5mm
JP13: Open; SolderJumper-2_P1.3mm_Open_RoundedPad1.0x1.5mm
Q6: BSS138; SOT-23; Manufacturer_Part_Number BSS138
R30: 1.6k; R_0603_1608Metric_Pad0.98x0.95mm_HandSolder; Manufacturer_Part_Number ERJ-3EKF1601V
R54: 21k; R_0603_1608Metric_Pad0.98x0.95mm_HandSolder; Manufacturer_Part_Number RC0603FR-0721KL
R60: 10k; R_0603_1608Metric_Pad0.98x0.95mm_HandSolder; Manufacturer_Part_Number 667-ERJ-3GEYJ103V; not fitted
RV3: Trim 2k; TC42X2202E; Manufacturer_Part_Number TC42X-2-202E; not fitted
U9: PTN78060W_EUW-7; Texas_EUW_R-PDSS-T7_THT; Manufacturer_Part_Number PTN78060WAD

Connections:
/Motor/5V: C86.1, C87.1, C118.1, C119.1, D5.2 (A), U9.5 (VO_Sense), U9.6 (VO); also elsewhere on the board
/Power/GPIO_ENABLE_POWER_SUPPLIES: Q6.1 (G), R60.1; also elsewhere on the board
/Power/Power_Buck_5V_Actuators/IN: C120.1, C121.1, C122.1, C123.1, C124.1, C125.1, U9.2 (VI); also elsewhere on the board
/Power/Power_Buck_5V_Actuators/TRIM: R54.1, U9.4 (VO_Adj)
GND: C86.2, C87.2, C118.2, C119.2, C120.2, C121.2, C122.2, C123.2, C124.2, C125.2, JP12.1 (A), Q6.2 (S), R30.2, R60.2, RV3.2, U9.1 (GND), U9.7 (GND); also elsewhere on the board
unnamed: D5.1 (K), R30.1
unnamed: JP12.2 (B), JP13.1 (A), R54.2
unnamed: JP13.2 (B), RV3.1
unnamed: Q6.3 (D), U9.3 (~Inhibit)

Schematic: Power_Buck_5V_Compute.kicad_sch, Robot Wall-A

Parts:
C51: 100uF; CAPPRD350W65D800H1250; Manufacturer_Part_Number EEU-FC1V101
C52, C53, C59, C60: 4.7uF/50V; C_1210_3225Metric_Pad1.33x2.70mm_HandSolder; Manufacturer_Part_Number GRM32ER71H475KA88L
C54: 10nF/50V; C_0805_2012Metric_Pad1.18x1.45mm_HandSolder; Manufacturer_Part_Number CL21B103KBANNNC
C55: 2.2uF/50V; C_1210_3225Metric_Pad1.33x2.70mm_HandSolder; Manufacturer_Part_Number C3225X7R1H225K250AB
C56, C57, C58: 47nF/50V; C_0603_1608Metric_Pad1.08x0.95mm_HandSolder; Manufacturer_Part_Number CC0603KPX7R9BB473
D16: LED_RED; LED_0603_1608Metric; Manufacturer_Part_Number LS L29K-G1J2-1
JP14: Closed; SolderJumper-2_P1.3mm_Bridged_RoundedPad1.0x1.5mm
JP15: Open; SolderJumper-2_P1.3mm_Open_RoundedPad1.0x1.5mm
R31: 1.6k; R_0603_1608Metric_Pad0.98x0.95mm_HandSolder; Manufacturer_Part_Number ERJ-3EKF1601V
R32: 21k; R_0603_1608Metric_Pad0.98x0.95mm_HandSolder; Manufacturer_Part_Number RC0603FR-0721KL
RV2: Trim 2k; TC42X2202E; Manufacturer_Part_Number TC42X-2-202E; not fitted
U10: PTN78060W_EUW-7; Texas_EUW_R-PDSS-T7_THT; Manufacturer_Part_Number PTN78060WAD

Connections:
/MCU/5V_PC_EMBARQUE: C51.1, C52.1, C53.1, C54.1, D16.2 (A), U10.6 (VO); also elsewhere on the board
/Power/Power_Buck_5V_Compute/5V_sense: U10.5 (VO_Sense); also elsewhere on the board
/Power/Power_Buck_5V_Compute/IN: C55.1, C56.1, C57.1, C58.1, C59.1, C60.1, U10.2 (VI); also elsewhere on the board
/Power/Power_Buck_5V_Compute/TRIM: R32.1, U10.4 (VO_Adj)
GND: C51.2, C52.2, C53.2, C54.2, C55.2, C56.2, C57.2, C58.2, C59.2, C60.2, JP14.1 (A), R31.2, RV2.2, U10.1 (GND), U10.7 (GND); also elsewhere on the board
unnamed: D16.1 (K), R31.1
unnamed: JP14.2 (B), JP15.1 (A), R32.2
unnamed: JP15.2 (B), RV2.1
unnamed 205: U10.3 (~Inhibit); also elsewhere on the board

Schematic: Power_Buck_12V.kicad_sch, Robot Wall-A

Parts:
C83, C85, C93, C117: 4.7uF/50V; C_1210_3225Metric_Pad1.33x2.70mm_HandSolder; Manufacturer_Part_Number GRM32ER71H475KA88L
C84: 330uF; CAPPRD500W65D1000H1800; Manufacturer_Part_Number EEU-FC1V331
C88: 10nF/50V; C_0805_2012Metric_Pad1.18x1.45mm_HandSolder; Manufacturer_Part_Number CL21B103KBANNNC
C89, C91, C92: 47nF/50V; C_0603_1608Metric_Pad1.08x0.95mm_HandSolder; Manufacturer_Part_Number CC0603KPX7R9BB473
C90: 2.2uF/50V; C_1210_3225Metric_Pad1.33x2.70mm_HandSolder; Manufacturer_Part_Number C3225X7R1H225K250AB
D7: LED_RED; LED_0603_1608Metric; Manufacturer_Part_Number LS L29K-G1J2-1
Q3: BSS138; SOT-23; Manufacturer_Part_Number BSS138
R39: 5.1k; R_0603_1608Metric_Pad0.98x0.95mm_HandSolder; Manufacturer_Part_Number CRCW06035K10FKEA
R41: 10k; R_0603_1608Metric_Pad0.98x0.95mm_HandSolder; Manufacturer_Part_Number 667-ERJ-3GEYJ103V; not fitted
R53: 549R; R_0603_1608Metric_Pad0.98x0.95mm_HandSolder; Manufacturer_Part_Number RC0603FR-07549RL
RV4: Trim 2k; TC42X2202E; Manufacturer_Part_Number TC42X-2-202E
U8: PTN78020W; Texas_EUK_R-PDSS-T7_THT; Manufacturer_Part_Number PTN78020WAD

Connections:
/Power/12V: C83.1, C84.1, C85.1, C88.1, D7.2 (A), U8.5 (VO_Sense), U8.6 (VO); also elsewhere on the board
/Power/GPIO_ENABLE_POWER_SUPPLIES: Q3.1 (G), R41.1; also elsewhere on the board
/Power/Power_Buck_12V/IN: C89.1, C90.1, C91.1, C92.1, C93.1, C117.1, U8.2 (VI); also elsewhere on the board
/Power/Power_Buck_12V/TRIM: R53.1, U8.4 (VO_Adj)
GND: C83.2, C84.2, C85.2, C88.2, C89.2, C90.2, C91.2, C92.2, C93.2, C117.2, Q3.2 (S), R39.2, R41.2, RV4.2, U8.1 (GND), U8.7 (GND); also elsewhere on the board
unnamed: D7.1 (K), R39.1
unnamed: Q3.3 (D), U8.3 (~Inhibit)
unnamed: R53.2, RV4.1

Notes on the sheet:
Si Vin=16V et Vout 5V --> Rendement >93% Avec un courant de 3A théorique (PC calcul) --> Puissance à dissiper de 1,05W Ne doit pas dépasser 55°C D'après la doc il ne faut pas forcément de radiateur, juste un ventilo Mettre un capteur de température pour monitorer?

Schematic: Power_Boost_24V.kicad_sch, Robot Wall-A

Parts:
C62, C69: 470uF/50V; CAPAE1700X1700N; Manufacturer_Part_Number EMVE500ARA471MLH0S
C63, C64, C65, C66, C67: 4.7uF/50V; C_0805_2012Metric_Pad1.18x1.45mm_HandSolder; Manufacturer_Part_Number GRM21BR61H475ME51L
C68: 10nF/50V; C_0805_2012Metric_Pad1.18x1.45mm_HandSolder; Manufacturer_Part_Number CL21B103KBANNNC
C70, C71, C72, C73, C74, C75, C76: 47nF/50V; C_0603_1608Metric_Pad1.08x0.95mm_HandSolder; Manufacturer_Part_Number CC0603KPX7R9BB473
C77, C78, C79, C80, C81: 4.7uF/50V; C_1210_3225Metric_Pad1.33x2.70mm_HandSolder; Manufacturer_Part_Number GRM32ER71H475KA88L
C82: 470pF; C_0603_1608Metric_Pad1.08x0.95mm_HandSolder; Manufacturer_Part_Number C0603C471K5RACTU
D6: LED_RED; LED_0603_1608Metric; Manufacturer_Part_Number LS L29K-G1J2-1
H7: ThermalPad; Manufacturer_Part_Number 404035125
H8: Heatsink; 374524B60023G; Manufacturer_Part_Number 374524B60023G
IC7: ABXS005A4X341-SRZ; ABXS005A4X341SRZ; Manufacturer_Part_Number ABXS005A4X341-SRZ
JP18: Closed; SolderJumper-2_P1.3mm_Bridged_RoundedPad1.0x1.5mm
JP19: Open; SolderJumper-2_P1.3mm_Open_RoundedPad1.0x1.5mm
Q2: BSS138; SOT-23; Manufacturer_Part_Number BSS138
R33: 11.3k; R_0603_1608Metric_Pad0.98x0.95mm_HandSolder; Manufacturer_Part_Number CRCW060311K3FKEA
R34: 200k; R_0603_1608Metric_Pad0.98x0.95mm_HandSolder; Manufacturer_Part_Number CRCW0603200KFKEC
R35: 100k; R_0603_1608Metric_Pad0.98x0.95mm_HandSolder; Manufacturer_Part_Number RCA0603100KFKEAHP
R36: 10k; R_0603_1608Metric_Pad0.98x0.95mm_HandSolder; Manufacturer_Part_Number 667-ERJ-3GEYJ103V; not fitted
R37: 10,553k/0.5%; R_0603_1608Metric_Pad0.98x0.95mm_HandSolder; Manufacturer_Part_Number RC0603DR-0710K5L
R38: 10k; R_0603_1608Metric_Pad0.98x0.95mm_HandSolder; Manufacturer_Part_Number 667-ERJ-3GEYJ103V
RV1: Trim 2k; TC42X2202E; Manufacturer_Part_Number TC42X-2-202E; not fitted
U2, U3: 125700D00000G; Manufacturer_Part_Number 125700D00000G

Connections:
/MCU/3V3: R36.2; also elsewhere on the board
/Power/24V: C62.1, C63.1, C64.1, C65.1, C66.1, C67.1, C68.1, D6.2 (A), IC7.2 (VOUT); also elsewhere on the board
/Power/GPIO_ENABLE_POWER_SUPPLIES: Q2.1 (G), R38.1; also elsewhere on the board
/Power/GPIO_PGOOD: IC7.13 (PGOOD), R36.1; also elsewhere on the board
/Power/Power_Boost_24V/ENABLE: IC7.12 (ENABLE), Q2.3 (D), R35.2
/Power/Power_Boost_24V/IN: C69.1, C70.1, C71.1, C72.1, C73.1, C74.1, C75.1, C76.1, C77.1, C78.1, C79.1, C80.1, C81.1, IC7.3 (VIN_1), IC7.5 (VIN_2), R35.1; also elsewhere on the board
/Power/Power_Boost_24V/SENSE+: IC7.10 (SENSE+), R34.2
/Power/Power_Boost_24V/TRIM: C82.1, IC7.11 (TRIM), R37.2
GND: C62.2, C63.2, C64.2, C65.2, C66.2, C67.2, C68.2, C69.2, C70.2, C71.2, C72.2, C73.2, C74.2, C75.2, C76.2, C77.2, C78.2, C79.2, C80.2, C81.2, IC7.1 (PGND_1), IC7.4 (PGND_2), IC7.6 (PGND_3), IC7.7 (SGND), JP18.1 (A), Q2.2 (S), R33.2, R38.2, RV1.2, U2.1, U2.2, U3.1, U3.2; also elsewhere on the board
unnamed: C82.2, R34.1
unnamed: D6.1 (K), R33.1
unnamed: JP18.2 (B), JP19.1 (A), R37.1
unnamed: JP19.2 (B), RV1.1

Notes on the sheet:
footprint size 10n --> 0805 47n --> 0603 4,7uF --> 1210
Anchors for heat sink Footprint placement : https://www.mouser.fr/datasheet/2/2/Aavid_01112021_Board_Level_Cooling_3745-1953702.pdf
Fan required minimum 3,5CFM
Si Vin=16V et Vout 24V --> Rendement >95% Avec un courant de 5A théorique --> Puissance à dissiper de 6W On ne compte pas les dT(°C/W) des gap filters car faibles (à vérifier!) Q1 ne doit pas dépasser 135°C (marge à 90°C pour sécurité) Si T ambiant de 30°C alors dT(°C/W) radiateur de (90-30)/6 = 10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

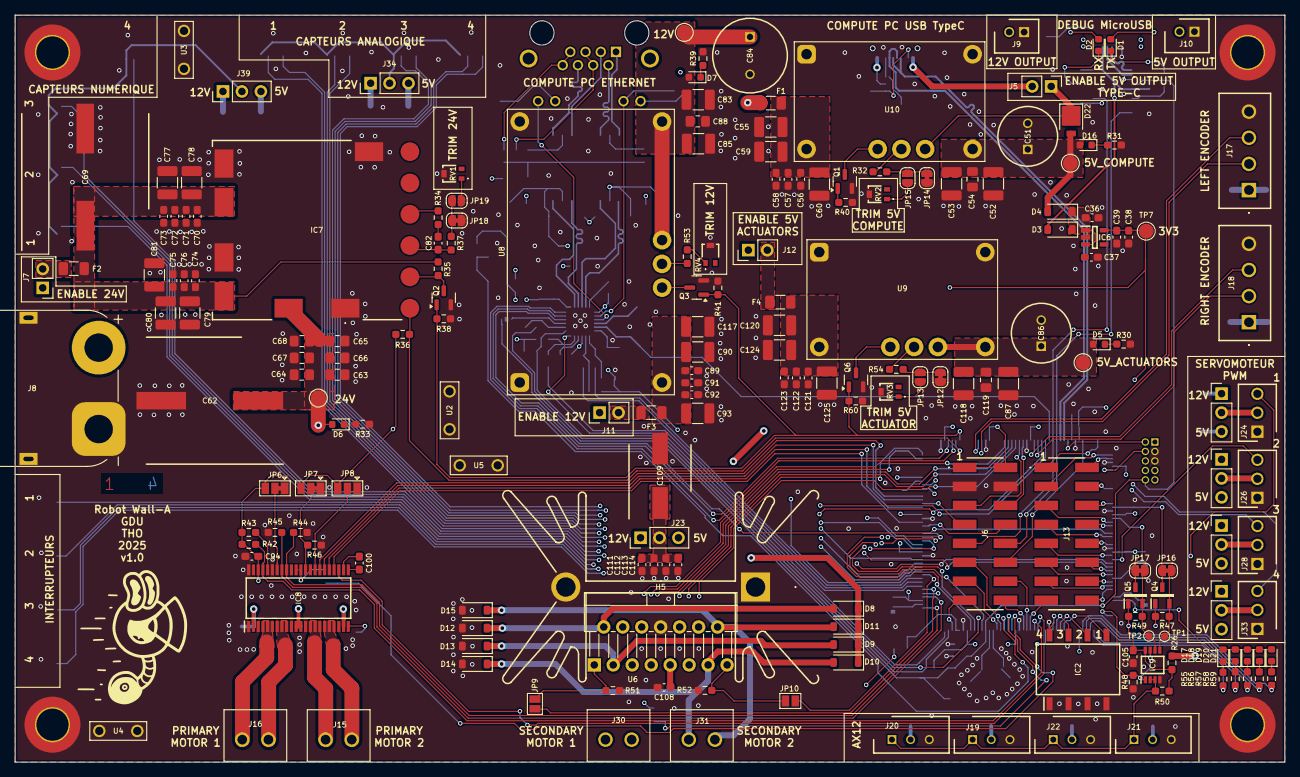
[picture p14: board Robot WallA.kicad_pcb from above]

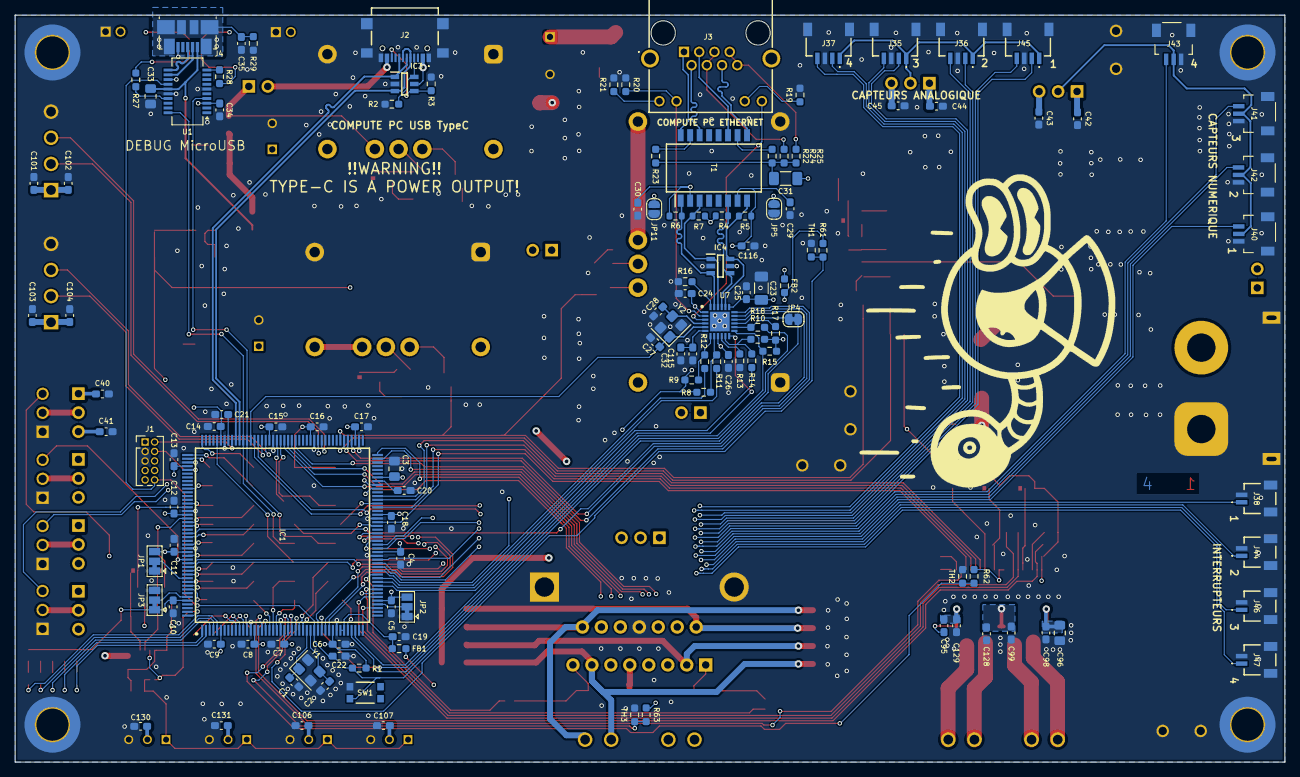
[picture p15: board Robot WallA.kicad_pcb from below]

Board: 4 copper layers, 170.0 x 100.0 mm, 328 parts (125 on the bottom side), 219 nets.

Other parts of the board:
Q1: BSS138; SOT-23
R40: 10k; R_0603_1608Metric_Pad0.98x0.95mm_HandSolder

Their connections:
/Power/Power_Buck_5V_Compute/GPIO_ENABLE: Q1.1 (G), R40.1
GND: Q1.2 (S), R40.2; also elsewhere on the board
unnamed 205: Q1.3 (D); also elsewhere on the board

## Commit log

2025-08-05 ADD: go go
    [Alimentation.kicad_sch, BoostBuck.kicad_sch, DriverMoteur.kicad_sch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]
2025-08-05 ADD: GPIO
    [GPIO.kicad_sch]
2025-08-05 ADD: Ethernet
    [Peripherals.kicad_sch]
2025-08-05 filled mototr driver schematic
    [DriverMoteur.kicad_sch]
2025-08-23 List of Modifs:
    Corrected power supply sheet
    Updated motor driver sheet
    Added a project name to a lot of sheets (don't know why...)
    [Alimentation.kicad_sch, BoostBuck.kicad_sch, Boost_24V.kicad_sch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]
2025-08-23 ADD supplies to UC
    [Boost_24V.kicad_sch, DriverMoteur.kicad_sch, MCU.kicad_sch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]
2025-08-25 Updated MCU sheet
    Added decoupling capacitors
    Linked Ethernet to MCU
    Started Usb linking to MCU
    [GPIO.kicad_sch, MCU.kicad_sch, MCU_Config.kicad_sch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]
2025-08-30 Updated a lot of stuff:
    Added encoders,
    Added 5V power supply for actuators
    Added 12V power supply for actuators
    Renamed sheets to be clearer
    Added usb debug
    Modify MCU sheet to be A3 format
    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
    [MCU.kicad_sch, MCU_Config.kicad_sch, MCU_Core.kicad_sch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]
2025-08-30 Renamed folder to be clearer (From PCB to Robot WallA)
    [MCU.kicad_sch, MCU_Config.kicad_sch, MCU_Core.kicad_sch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]
2025-08-30 Continued to link MCU pins, Added a sheet for servomotors and optional 2 DC motors.
    [MCU.kicad_sch, MCU_Config.kicad_sch, MCU_Core.kicad_sch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]
2025-08-31 Defined every footprints
    [DistanceMeter.kicad_sch, MCU.kicad_sch, MCU_Config.kicad_sch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]
2025-09-01 Created sensors sheet (for distance meters and others)
    [DistanceMeter.kicad_sch, Robot WallA.kicad_sch, Sensors.kicad_sch]
2025-09-01 Startes to write README
    [Robot WallA.kicad_sch]
2025-09-01 Updated README and add jumper part reference
    [Power.kicad_sch]
2025-09-02 Updated USB UART converter, Linked telemeter sensors.
    Updated components indicators
    [MCU.kicad_sch, MCU_Core.kicad_sch, MCU_Debug.kicad_sch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]
2025-09-06 Added standard switchs, debug leds and 12V and 5V connectors
    [MCU.kicad_sch, MCU_Core.kicad_sch, Motor.kicad_sch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]
2025-09-08 Begin to route ethenet, usb, 24V power supply.
    Reworked Ethernet sheet because it was too hard to read
    [MCU_GPIO.kicad_sch, MCU_Peripherals.kicad_sch, Robot WallA.kicad_pcb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]
2025-09-08 Continue to route
    [MCU_Debug.kicad_sch, Motor_Actuators.kicad_sch, Motor_WheelDriver.kicad_sch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]
2025-09-13 Reworked 12V and 5V power supplies, continue routing
    [Motor_WheelDriver.kicad_sch, Power_Buck_12V.kicad_sch, Power_Buck_5V_Actuators.kicad_sch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]
2025-09-15 Conitnue routing
    [MCU_Core.kicad_sch, MCU_GPIO.kicad_sch, MCU_Peripherals.kicad_sch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]
2025-09-20 Correct a lot of error in DRC
    [MCU.kicad_sch, MCU_Core.kicad_sch, MCU_GPIO.kicad_sch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]
2025-09-20 Corrected all DRC erros, added info on PCB
    modified distance meter connectors to be horizontal
    [MCU.kicad_sch, MCU_Core.kicad_sch, MCU_GPIO.kicad_sch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]
2025-09-20 Updated fab files.
    [MCU.kicad_sch, MCU_Config.kicad_sch, MCU_Core.kicad_sch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]
2025-09-20 Moved 24V boost to be correct assembly issue with heatsink fixation collisions
    [Robot WallA.kicad_pcb]
2025-09-21 Added diode for Type-C connector in case we accidentally power the board with this connector.
    Updated fab files
    [MCU.kicad_sch, MCU_Core.kicad_sch, MCU_Peripherals.kicad_sch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]
2025-09-21 Added to BOM connectors and socket
    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
    [MCU_Config.kicad_sch, MCU_Core.kicad_sch, MCU_Debug.kicad_sch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]
2025-09-21 Modified a bit pin header pins to allow I2C,SPI and CAN
    [MCU.kicad_sch, MCU_Core.kicad_sch, MCU_GPIO.kicad_sch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]
2025-09-21 Updated Fab files
    [MCU_GPIO.kicad_sch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]
2025-09-21 Added pin header for 5V USB type output, to be able to disable it
    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
    [MCU_Peripherals.kicad_sch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]
2025-09-23 Added 3 thermistor to measure temperature near 12V and 24V power supplies and near motor drivers
    [MCU.kicad_sch, MCU_Core.kicad_sch, MCU_GPIO.kicad_sch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]
2025-09-23 Modified footprint to simplify BOM. Finalized BOM.
    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
    [MCU_Config.kicad_sch, MCU_Core.kicad_sch, MCU_Debug.kicad_sch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]
2025-09-23 Added Thermal pads for heatsinks in BOM.
    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
    [Motor_Actuators.kicad_sch, Motor_WheelDriver.kicad_sch, Power_Boost_24V.kicad_sch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]
2025-10-08 Added a trim to 24V in case of (defaulty unplaced)
    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
    [Power_Boost_24V.kicad_sch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]
2025-10-10 Finalized BOM
    [Robot WallA.xlsx]
2025-10-15 Added logo
    Replaced out of stock components
    [MCU_Peripherals.kicad_sch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]
2025-10-15 Moved Debug LEDs to be on top layer.
    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
    [Robot WallA-B_Cu.gbr, Robot WallA-B_Mask.gbr, Robot WallA-B_Paste.gbr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]
2026-05-09 Corrected schematic labels encoders according to PCB labels... (inversion...)
    Add fab files
    cleaned
    [MCU_Core.kicad_sch, Motor_Actuators.kicad_sch, Motor_Encoders.kicad_sch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]
2026-05-09 updated schematic pdf
